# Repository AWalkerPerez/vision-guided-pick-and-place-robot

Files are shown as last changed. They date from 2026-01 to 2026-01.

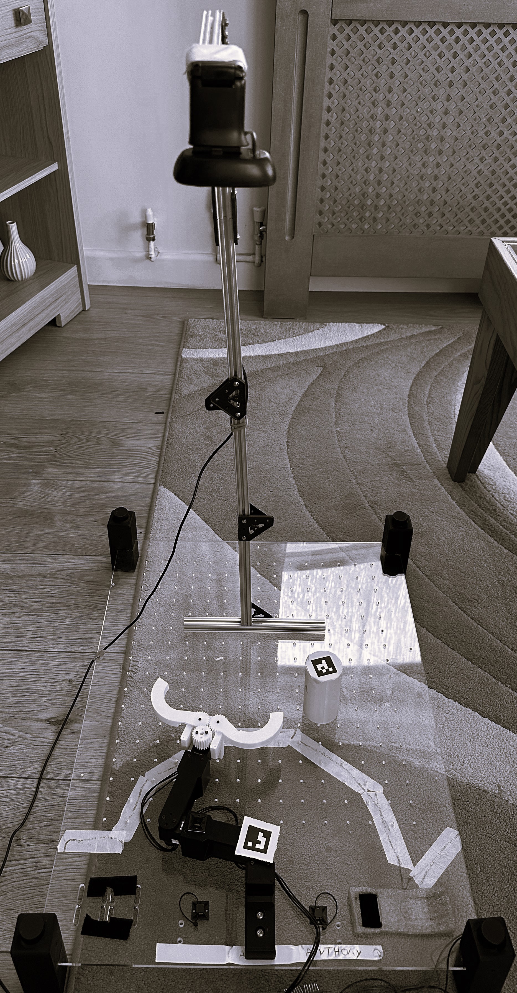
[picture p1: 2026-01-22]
media/photos/setup.jpg

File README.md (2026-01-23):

# Vision-Guided Pick-and-Place Robot (3-DOF)

Autonomous 3-DOF pick-and-place robot using **vision-based control** (ArUco markers) to localise objects and drive the robot end-effector using **inverse kinematics** (DLS / Jacobian-based control).  
This repository contains the full project deliverables: source code, CAD, calibration notes, diagrams, media, and the final report.

> ⚠️ This project is **hardware-dependent** (camera + robot). It is not designed to be simulation-only out of the box.

---

## Project overview

**Pipeline (high level):**
1. Camera captures frames of the workspace.
2. ArUco markers are detected → object pose is estimated in the camera frame.
3. Pose is transformed into the robot/world frame using calibration.
4. A controller computes joint updates (e.g., Damped Least Squares IK) to move to target.
5. Gripper/clamp action closes/opens at the right time.
6. Optional behaviours: obstacle avoidance, multi-object sequencing, homing.

---

## Repository layout

```text
vision-guided-pick-and-place-robot/
├── README.md
├── .gitignore
├── environment.md
├── setup.md
├── calibration.md
│
├── report/
│   └── AUTONOMOUS_3DOF_PICK-AND-PLACE_ROBOT_USING_VISION-BASED_CONTROL.pdf
│
├── src/
│   ├── README.md
│   ├── (your Python/ROS scripts live here)
│   └── (configs / launch / helpers depending on your implementation)
│
├── cad/
│   ├── README.md
│   └── (Fusion 360 source + exports: .f3d/.f3z, .step, .stl, .3mf)
│
├── diagrams/
│   ├── README.md
│   └── (system diagrams, flowcharts, architecture images)
│
├── media/
│   ├── README.md
│   ├── photos/
│   └── videos/
│
└── docs/
    ├── README.md
    └── (optional: extra notes, troubleshooting, design decisions)
```

---

## Quick start
### 1) Read the setup docs
- Hardware + software setup: see `setup.md`
- Environment / dependencies: see `environment.md`
- Calibration process: see `calibration.md`

### 2) Run the project (hardware required)
The entrypoint depends on how your `src/` scripts are structured (ROS nodes vs. standalone scripts).
Go to `src/README.md` for the exact run commands.

---

## Calibration
Calibration is required to map camera measurements into the robot coordinate frame and to get stable pose estimates.
See:
- `calibration.md`
- Marker PDF / reference: `aruco_markers_25mm.docx`

---

## Results & media
- Photos and videos are under `media/`.
- Diagrams and pipeline visuals are under `diagrams/`.
- Full report (methods, experiments, results): `report/`.

---

## Notes on reproducibility
Because this is a physical system, results depend on:
- camera placement + intrinsics,
- lighting conditions,
- robot assembly tolerances,
- motor tuning / controller gains,
- marker size + print quality.
The report documents the tested configuration and evaluation.

---

## Citation
If you use or reference this work, please cite the project report in `report/`.

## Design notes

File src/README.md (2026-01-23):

# src

Core ROS 2 (Python) scripts for the **vision-guided 3DOF pick-and-place robot**.

This project is **hardware-first** (camera + Dynamixel/OpenRB-150 + physical robot).  
There is no simulation workflow provided.

---

## Files

### ROS 2 nodes
- `camera_publisher.py`  
  Publishes camera frames.
  - Publishes: `camera/image` (`sensor_msgs/Image`)

- `aruco_pose.py`  
  Detects ArUco markers in `camera/image`, computes each marker pose **relative to marker ID 0**, and publishes a topic per marker ID.
  - Subscribes: `camera/image`
  - Publishes: `desired_pos_<id>` (`std_msgs/Float32MultiArray`) e.g. `desired_pos_7`
  - Parameter: `marker_size` (default **0.025 m** = 25 mm)

- `marker_tracking.py`  
  High-level **pick-and-place state machine**.
  - Subscribes: `joint_state` and dynamically subscribes to `desired_pos_<id>` topics
  - Publishes: `joint_pos`, `cartesian_pos`, `gripper_command`
  - Two stages:
    - **Stage 1 (recording):** records desired goal positions from **even marker IDs**
    - **Stage 2 (moving):** tracks objects from **odd marker IDs**
  - Pairing rule used in code:
    - Object marker `X` (odd) uses goal marker `(X + 1)` (even)

- `control_dls.py`  
  Damped Least Squares (DLS) IK controller: Cartesian target → joint targets.
  - Subscribes: `joint_state`
  - Publishes: `joint_pos`, `cartesian_pos`

- `hardware_interface.py`  
  Hardware bridge for Dynamixels via OpenRB-150.
  - Publishes: `/joint_state`, `/cartesian_pos`, `/ee_min_max`, `/emergency_stop`
  - Subscribes: `/joint_pos`, `/joint_vel`, `/joint_cur`, `/joint_pos_rel`, `/gripper_command`

### Utility (not a ROS node)
- `cameraCalibration.py`  
  Chessboard calibration utility. Saves intrinsics to `calibration.npz`.

---

## Marker pose message format (important)

`aruco_pose.py` publishes a `Float32MultiArray` with 6 values:

`[x_mm, y_mm, z_mm, roll_deg, pitch_deg, yaw_deg]`

In the current implementation, the first two values are published as:

- `msg.data[0] = relative_y_mm`
- `msg.data[1] = relative_x_mm`

`marker_tracking.py` then uses only the first two values:

- `pos = [msg.data[0], msg.data[1]]`
- `yaw = msg.data[5]`

So the system is internally consistent, but note the **X/Y ordering** is “swapped” compared to some comments.

---

## Calibration (required)

`aruco_pose.py` loads calibration like this:

```python
np.load("calibration.npz")
```
So the simplest workflow is to generate the file in the repo root and run nodes from the repo root.

Generate calibration:
```bash
python3 src/cameraCalibration.py
```
This creates:
`calibration.npz` (in your current working directory)

---

## Running the system (typical order)
Open separate terminals and ensure ROS 2 is sourced in each.

### 1) Camera publisher
```bash
python3 src/camera_publisher.py
```
### 2) Marker detection
```bash
python3 src/aruco_pose.py
```
### 3) Hardware interface (robot must be connected)
```bash
python3 src/hardware_interface.py
```
### 4) Autonomy / control
You typically run the pick-and-place state machine (and optionally DLS control depending on your test):
```bash
python3 src/marker_tracking.py
```
Optional (if you use the DLS node separately):
```bash
python3 src/control_dls.py
```

---

## Debugging quick commands
List topics:
```bash
ros2 topic list
```
Echo key topics:
```bash
ros2 topic echo /joint_state
ros2 topic echo desired_pos_0
ros2 topic echo desired_pos_1
```

---

## Common issues
**- No markers detected**

    - Check lighting / focus
    
    - Confirm printed marker size matches marker_size (25mm default)
    
    - Confirm calibration.npz exists where you run aruco_pose.py
    
    - Robot moves wrong direction / mirrored
    
    - Double-check the X/Y ordering (see message format section)
    
    - Verify camera mounting orientation and coordinate assumptions

**- Motors not responding**

    - Check device connection/permissions/port configuration inside hardware_interface.py
    
    - Confirm motor IDs and baud rate match your hardware setup

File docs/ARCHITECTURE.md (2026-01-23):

# System Architecture

This repo implements a **hardware-first** vision-guided pick-and-place pipeline for a 3DOF robot arm using:
- a top-down USB camera
- ArUco marker detection + pose estimation
- Jacobian-based IK control (Damped Least Squares)
- Dynamixel actuation via OpenRB-150
- ROS 2 (Python)

The system is split into small ROS 2 nodes that communicate via topics.

---

## Components (scripts)

The `src/` folder contains:

- `camera_publisher.py` — publishes camera frames
- `aruco_pose.py` — detects markers and publishes per-marker pose topics (`desired_pos_<id>`)
- `marker_tracking.py` — pick-and-place logic / state machine (records targets, then moves)
- `control_dls.py` — IK control (DLS) (Cartesian target → joint targets)
- `hardware_interface.py` — Dynamixel/OpenRB hardware bridge (commands + feedback + safety)
- `cameraCalibration.py` — offline chessboard calibration (creates `calibration.npz`)

---

## ROS 2 nodes and topics

### 1) Camera Publisher (`camera_publisher.py`)
**Role:** Captures frames and publishes them for vision.

- **Publishes**
  - `camera/image` (`sensor_msgs/Image`)

---

### 2) Vision / Marker Pose (`aruco_pose.py`)
**Role:** Detects markers in the camera stream and publishes their relative pose.

- **Subscribes**
  - `camera/image` (`sensor_msgs/Image`)

- **Publishes (dynamic)**
  - `desired_pos_<marker_id>` (`std_msgs/Float32MultiArray`)
  - Example topics: `desired_pos_0`, `desired_pos_1`, `desired_pos_7`, ...

**Calibration dependency**
- Loads camera intrinsics from `calibration.npz` (generated by `cameraCalibration.py`).

**Reference frame convention**
- Marker **ID 0** is used as a **reference**.
- For each detected marker, it computes pose **relative to marker 0** and publishes that.

**Message layout**
Published as `Float32MultiArray` with 6 values:
`[msg.data[0], msg.data[1], msg.data[2], msg.data[3], msg.data[4], msg.data[5]]
= [axis1_mm, axis2_mm, z_mm, roll_deg, pitch_deg, yaw_deg]`

> Note: In the current implementation the first two axes are swapped compared to the comment in-code,
> but downstream nodes treat the first two entries consistently as the “2D target position”.

---

### 3) Task Logic / State Machine (`marker_tracking.py`)
**Role:** Coordinates the autonomous behavior:
- “recording” stage: record desired goal positions
- “moving” stage: track object positions, then pick-and-place

**Dynamic subscription**
- It scans the ROS graph and automatically subscribes to any topic matching:
  - `desired_pos_<id>` or `/desired_pos_<id>`

**Marker ID convention**
- **Even marker IDs** represent **desired goal positions** (recorded during “recording” stage).
- **Odd marker IDs** represent **object markers** (tracked during “moving” stage).
- The logic pairs them like:
  - object marker `X` uses desired goal stored under marker `(X + 1)`

**Subscribes**
- `joint_state` (from hardware interface)
- `desired_pos_<id>` topics (dynamic)

**Publishes**
- `joint_pos`
- `cartesian_pos`
- `gripper_command`

---

### 4) IK Control (`control_dls.py`)
**Role:** Converts Cartesian target motion into joint commands using **Damped Least Squares**.

**Subscribes**
- `joint_state`

**Publishes**
- `joint_pos`
- `cartesian_pos`

---

### 5) Hardware Interface (`hardware_interface.py`)
**Role:** Bridge to the **physical** Dynamixel/OpenRB system:
- publishes joint feedback
- listens for motion / gripper commands
- provides safety topics

**Publishes**
- `/joint_state`
- `/cartesian_pos`
- `/ee_min_max`
- `/emergency_stop`

**Subscribes**
- `/joint_pos`
- `/joint_vel`
- `/joint_cur`
- `/joint_pos_rel`
- `/gripper_command`

> Important: Some nodes use topic names without a leading `/` (e.g. `joint_pos`),
> while the hardware node subscribes to `/joint_pos`.
> If messages don’t flow, standardise names (either always `/topic` or always `topic`)
> or check what’s actually active with `ros2 topic list`.

---

## Data-flow diagram (high level)
```
                ┌───────────────────────┐
                │    camera_publisher   │
                │  (USB/RGB camera node)│
                └───────────┬───────────┘
                            │  /camera/image
                            v
                ┌───────────────────────┐
                │    aruco_detector     │
                │ (detect IDs + pose)   │
                └───────────┬───────────┘
                            │  /aruco/poses   (pose(s) of marker(s) in camera frame)
                            v
                ┌───────────────────────┐
                │   marker_tracking     │
                │ (select target ID,    │
                │  filter/smooth pose,  │
                │  transform to robot)  │
                └───────────┬───────────┘
                            │  /target_pose   (desired end-effector pose in robot/base frame)
                            v
                ┌───────────────────────┐
                │      control_dls      │
                │ (IK / DLS / Jacobian  │
                │  -> joint commands)   │
                └───────────┬───────────┘
                            │  /joint_cmd     (q_des or dq_des)
                            v
                ┌───────────────────────┐
                │   hardware_interface  │
                │ (send to motors, read │
                │  encoders)            │
                └───────┬───────┬───────┘
                        │       │
          /joint_state  │       │  /gripper_cmd
 (q, dq feedback)       │       │  (open/close)
                        │       │
                        v       v
                ┌───────────────────────┐
                │    control_dls uses   │
                │  /joint_state feedback│
                └───────────────────────┘
```
---

## Execution order (typical)

1. `camera_publisher.py`
2. `aruco_pose.py`  (requires `calibration.npz`)
3. `hardware_interface.py` (requires physical robot connection)
4. `control_dls.py` and/or `marker_tracking.py`

---

## Suggested improvements (optional)
- Standardise topic naming (`/joint_pos` vs `joint_pos`) across all scripts.
- Replace `Float32MultiArray` for marker pose with `geometry_msgs/PoseStamped` (clearer + safer).
- Publish transforms (`tf2_ros`) for `camera → base` and marker frames for easier debugging.

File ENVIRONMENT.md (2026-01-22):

# Environment

This project is a hardware-integrated ROS2 system (camera + AprilTags + Dynamixel motors via OpenRB-150).  
It is not simulation-first; you will need the physical robot setup (or equivalent hardware) to run the full stack.

## Tested platform
- Host OS: Ubuntu (recommended: 22.04 or newer)
- ROS 2: Iron (recommended)
- Python: 3.x (ROS2 system Python)

## Core dependencies
### ROS 2 packages (typical)
- `rclpy`
- `sensor_msgs`, `geometry_msgs`, `std_msgs`
- `tf2_ros`
- `cv_bridge` (if using ROS image transport + OpenCV)
- `image_transport` (optional)

### Python packages
- `numpy`
- `opencv-python` (or system OpenCV depending on ROS install)
- AprilTag detection (one of the following depending on your implementation):
  - `apriltag` (Python wrapper), or
  - `pupil_apriltags`, or
  - OpenCV AprilTag module (if available in your build)

### Motor / hardware interface
- Dynamixel control stack as used in this project (OpenRB-150 + Dynamixel SDK / ROS wrapper depending on your implementation)

## Notes
- If you are using ROS-installed OpenCV/cv_bridge, prefer system packages over pip OpenCV to avoid ABI conflicts.
- For large binaries (videos/CAD), consider Git LFS.

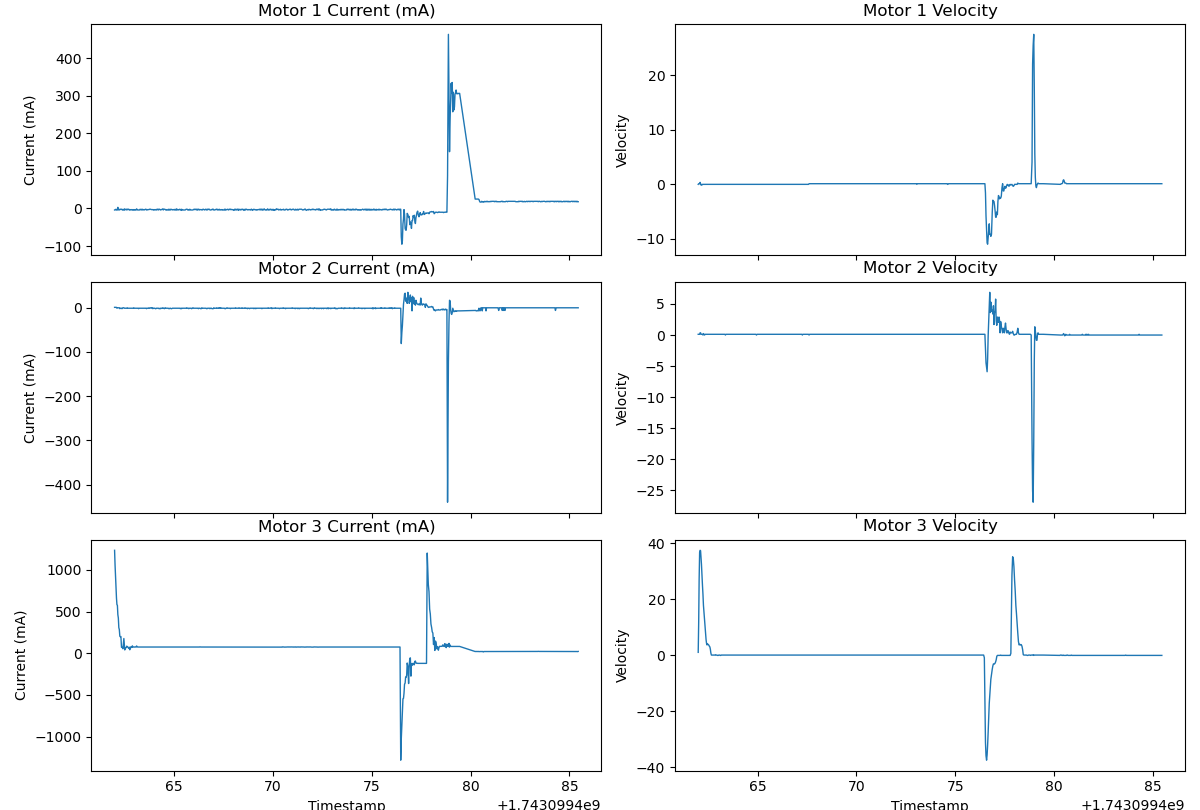
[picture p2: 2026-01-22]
docs/diagrams/motor_thresholds_200.png

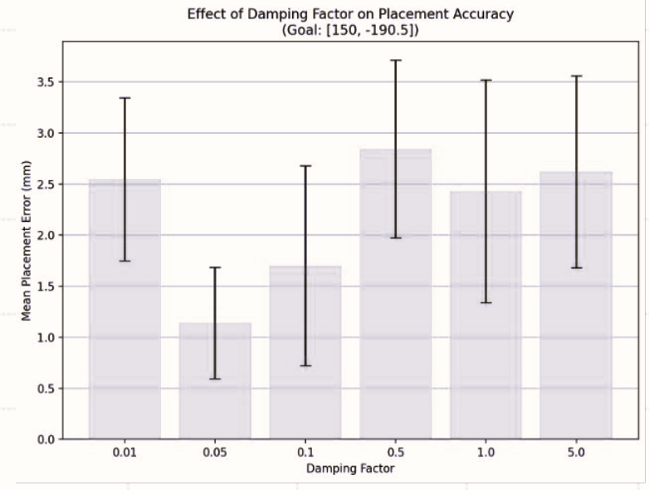
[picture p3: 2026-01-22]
docs/diagrams/damping_factor_acc_err.png

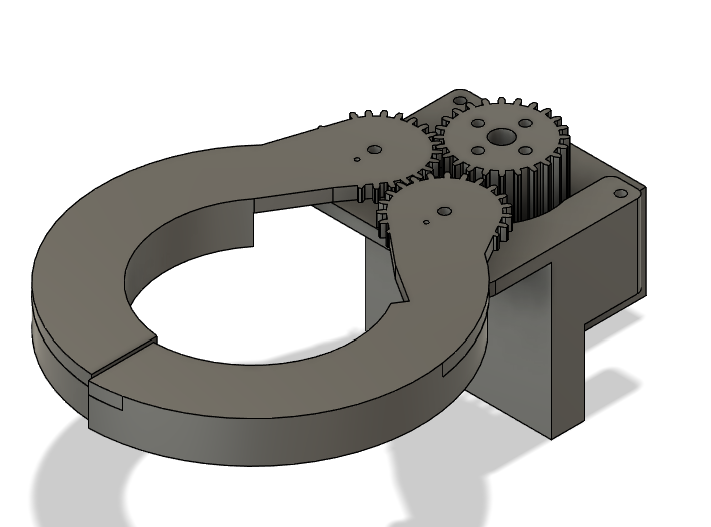
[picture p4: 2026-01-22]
media/photos/cad_end_effector.png

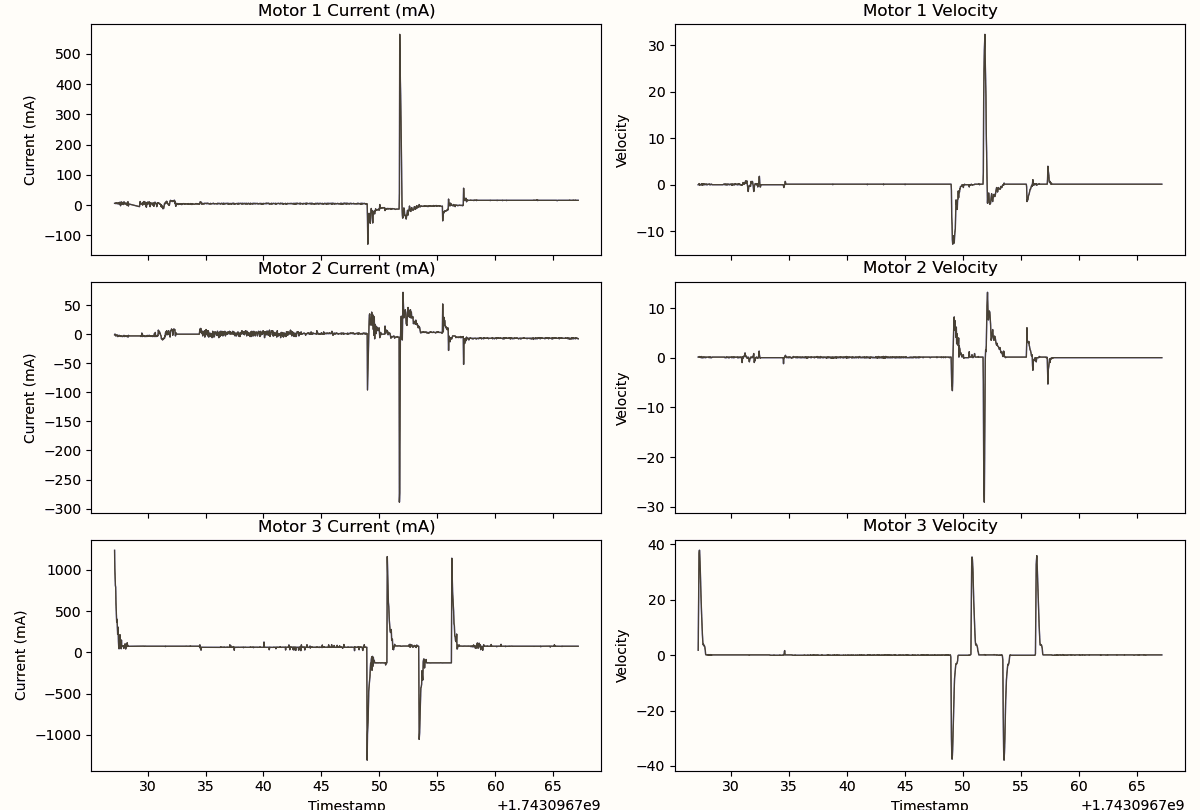
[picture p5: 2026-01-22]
docs/diagrams/motor_thresholds_no_force.png

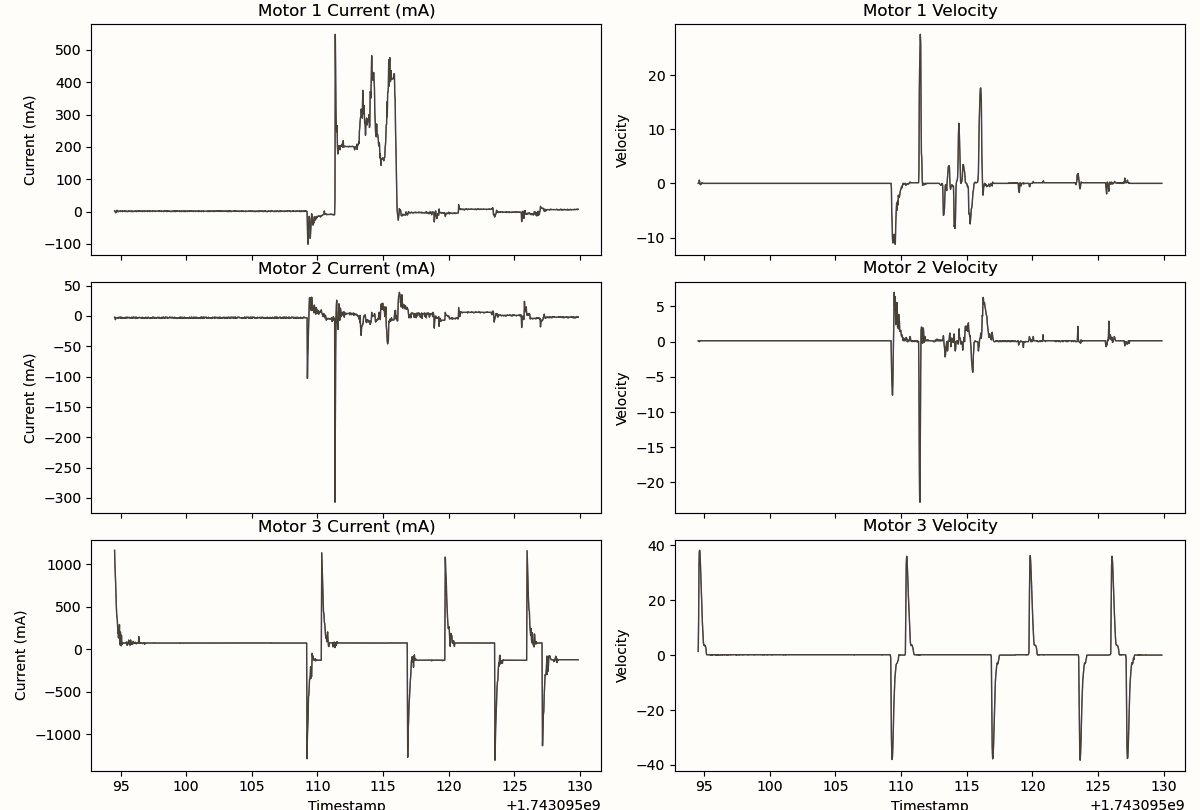
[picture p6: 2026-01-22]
docs/diagrams/motor_thresholds_force_no_threshold.png

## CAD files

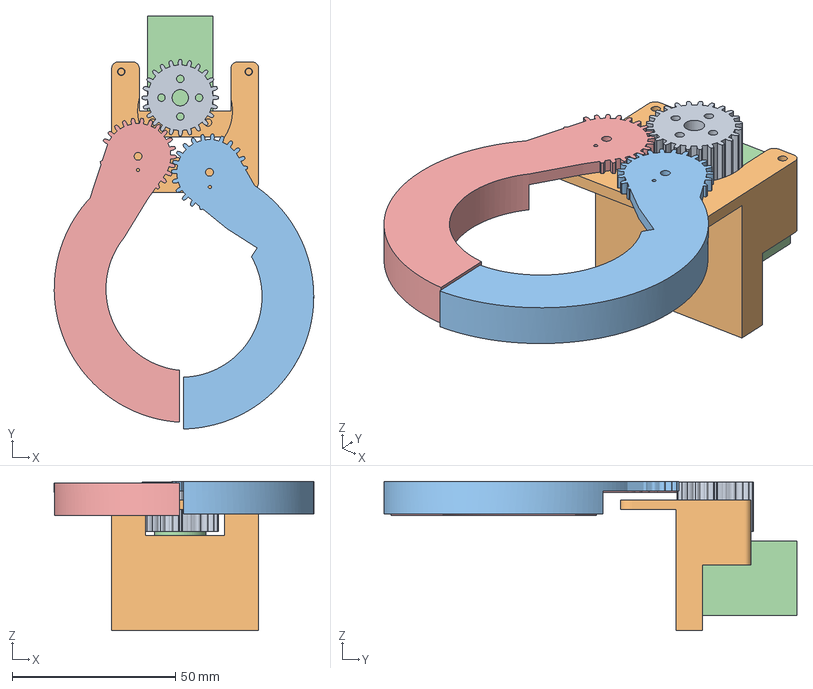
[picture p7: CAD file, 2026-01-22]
cad/printing_files/3mf/final_assembly.3mf
79.4 x 126.3 x 45.7 mm

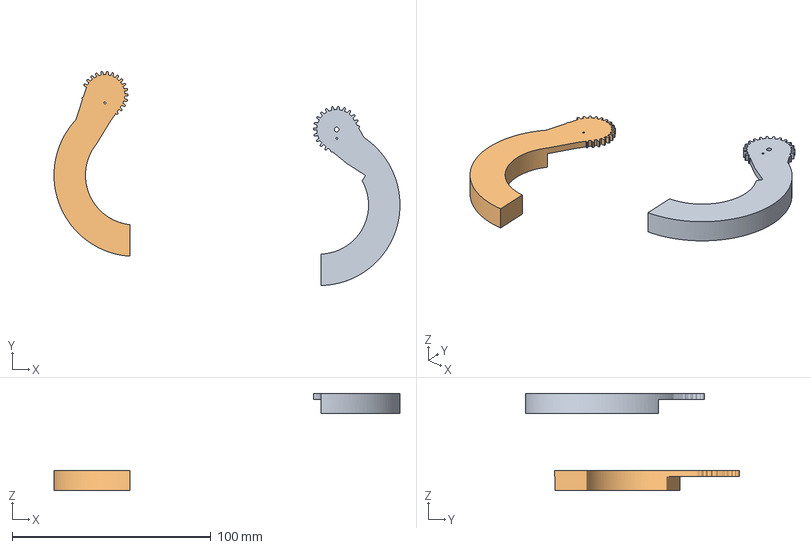
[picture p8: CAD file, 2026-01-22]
cad/printing_files/3mf/arm.3mf
174.1 x 107.7 x 48.8 mm

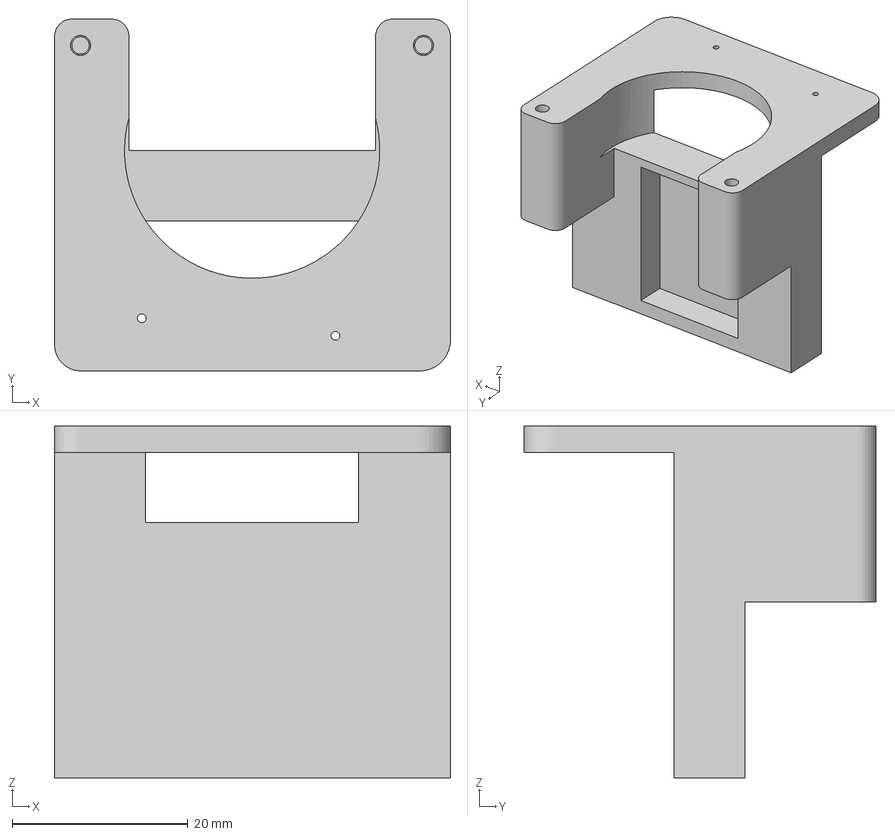
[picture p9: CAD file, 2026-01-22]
cad/printing_files/3mf/middle_piece.3mf
45.0 x 40.0 x 40.0 mm

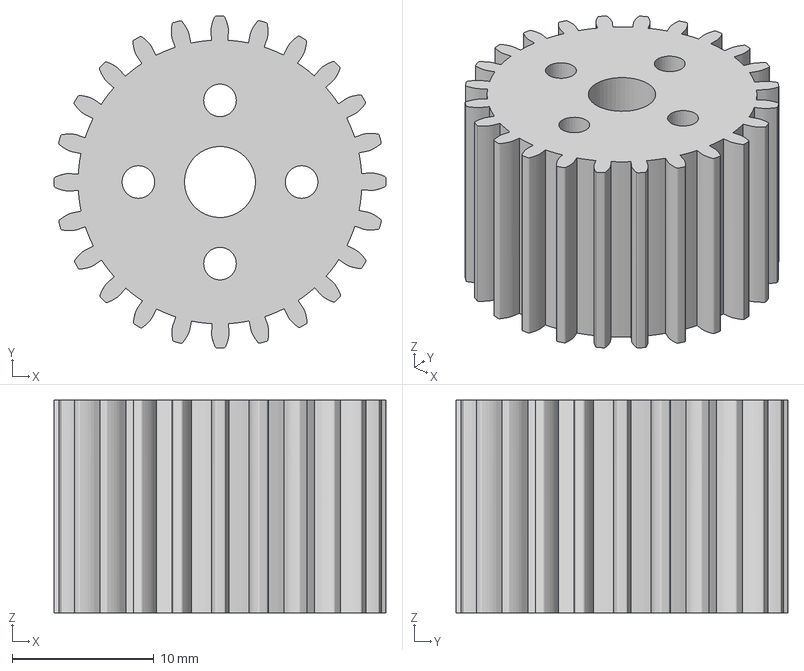
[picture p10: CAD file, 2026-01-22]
cad/printing_files/3mf/gear.3mf
23.4 x 23.4 x 15.0 mm

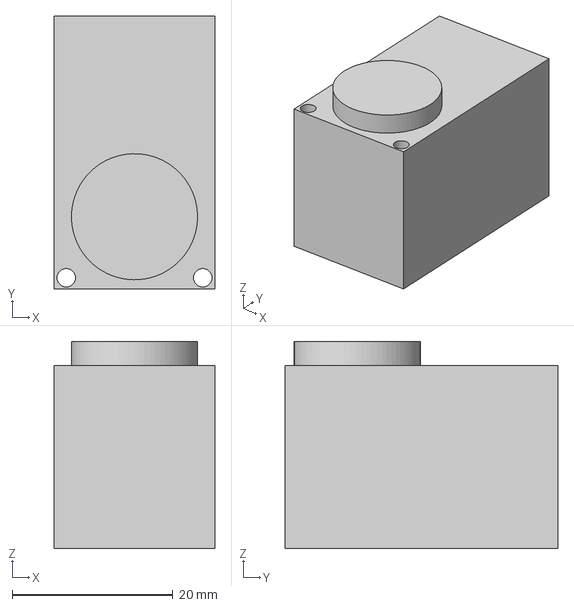
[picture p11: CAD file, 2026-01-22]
cad/printing_files/3mf/gear_holder.3mf
20.0 x 34.0 x 25.8 mm

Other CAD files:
cad/fusion360/arm.f3d
cad/fusion360/final_assembly.f3d
cad/fusion360/gear.f3d
cad/fusion360/gear_holder.f3d
cad/fusion360/middle_piece.f3d
cad/printing_files/stl/arm.stl
cad/printing_files/stl/final_assembly.stl
cad/printing_files/stl/gear.stl
cad/printing_files/stl/gear_holder.stl
cad/printing_files/stl/middle_piece.stl

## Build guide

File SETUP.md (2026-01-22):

# Setup

This repo contains a ROS2-based pick-and-place system that uses:
- A USB camera (Logitech)
- AprilTags for object detection / pose estimation
- A 3DOF arm actuated by Dynamixel motors via OpenRB-150
- Motion control using Jacobian-based IK (e.g., DLS / Jacobian Transpose depending on mode)

> This project requires hardware to run end-to-end.

---

## Hardware prerequisites
- Raspberry Pi 4 (or equivalent controller running ROS2 nodes / motor interface)
- OpenRB-150 interface board
- Dynamixel motors (as per your build)
- Motorised clamp end-effector
- USB camera (Logitech) mounted above workspace
- Printed AprilTags (see `/aruco_markers_25mm.docx` or your marker assets)
- A flat workspace with known scale + tag placement

---

## Software prerequisites
1. Install ROS2 (recommended: Iron) on the main machine(s)
2. Clone this repo
3. Install Python dependencies used by the vision/control nodes (see `environment.md`)

---

## Typical run flow (high level)
1. **Camera node**
   - Starts capturing frames and publishing images as ROS topics.

2. **Vision node**
   - Detects AprilTags, publishes tag poses (and/or TF frames).

3. **Control node**
   - Converts tag poses into target end-effector poses.
   - Runs IK (DLS / Jacobian methods) to generate joint commands.

4. **Motor interface**
   - Sends position/velocity commands to Dynamixels.
   - Reads motor feedback (current/velocity) for safety + collision handling.

---

## Calibration (recommended)
- Camera intrinsics calibration (checkerboard)
- Verify tag size matches your printed markers (e.g., 25mm / 50mm)
- Verify coordinate frames:
  - camera frame
  - world/workspace frame
  - base frame
  - end-effector frame

See: `docs/calibration.md` (create this if you don’t already have it)

---

## Safety notes
- Always test with reduced speed first.
- Ensure current-limits / stall detection is enabled before autonomous sequences.
- Keep a physical emergency stop procedure (unplug power / disable torque).

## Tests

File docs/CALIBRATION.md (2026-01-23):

# Camera Calibration (Required)

This project estimates ArUco/AprilTag marker pose from a top-down USB camera.  
To get accurate pose estimates, you must calibrate the camera intrinsics and ensure the marker size in code matches the printed markers.

Calibration is performed using:
- `src/cameraCalibration.py` (chessboard calibration)
- output file: `calibration.npz`
- used by: `src/aruco_pose.py`

---

## What calibration produces

`calibration.npz` stores:
- `camMatrix` — camera intrinsic matrix (fx, fy, cx, cy)
- `distCoef` — lens distortion coefficients

These are required for accurate marker pose estimation and stability.

---

## Prerequisites

- A printed chessboard calibration target
- Good lighting and a stable camera mount
- Python + OpenCV installed (the same OpenCV used by your project)
- A set of calibration images (or live capture, depending on how your script is written)

---

## Step 1 — Print a chessboard target

Print a chessboard pattern on A4/A3.
- Print at **100% scale** (no “fit to page”).
- Mount it flat (cardboard helps) to avoid warping.

> If your `cameraCalibration.py` expects a specific chessboard size (e.g., 7×9 corners), keep the print consistent with that.

---

## Step 2 — Capture calibration images

You need multiple images of the chessboard from different positions and angles:
- Move the chessboard across the entire camera view (corners + edges + center)
- Vary the tilt slightly (to help solve intrinsics)
- Keep the chessboard sharp and well-lit
- Avoid motion blur

Recommended: **20–40 images** minimum.

---

## Step 3 — Run calibration

From the repo root:

```bash
python3 src/cameraCalibration.py
```
This should generate:
`calibration.npz`

### Where to place calibration.npz
`aruco_pose.py` loads calibration using a relative path:

```python
np.load("calibration.npz")
```
So you have two safe options:

**Option A (simplest):** put `calibration.npz` in the repo root
✅ Works if you run scripts from the repo root.

**Option B (also fine):** put `calibration.npz` next to the script
Place it in `src/` and run `aruco_pose.py` from inside `src/`.

If you want this to be robust regardless of working directory, update `aruco_pose.py` to load calibration using an absolute path (recommended improvement).

---

## Step 4 — Verify calibration quality
After calibration, check:

### A) Visual sanity checks
- Marker detections should be stable (no sudden jumps when marker is static)
- Pose should not “flip” randomly
- Estimated distance should be reasonable (not off by 2×)

### B) Quick quantitative checks (optional)
Many calibration scripts print:
- RMS reprojection error
As a rough guide:
- **< 1.0 px** is usually decent for a typical webcam setup
- **< 0.5 px** is very good
- If it’s large (> 2–3 px), retake images with better lighting/sharpness

---

## Step 5 — Marker size consistency (very important)
Your marker size must match the printed tags.
- Printed marker document: `docs/aruco_markers_25mm.docx`
- If you use a different size (e.g., 50mm), update the marker size parameter in the vision code.
If marker size is wrong, you will see:
- incorrect depth / scale (distance estimates wrong)
- pick-and-place accuracy degraded

---

## Common issues & fixes
### “Markers detected but pose is noisy / jittery”
- Increase lighting
- Reduce motion blur (faster shutter / brighter scene)
- Ensure camera is rigidly mounted (no vibration)
- Improve calibration image quality (more images, better coverage)

### “Pose scale seems wrong”
- Marker size in code does not match printed marker size
- Chessboard print is not at 100% scale
- Wrong chessboard square size used in calibration (if your script uses square size)

### “aruco_pose.py can’t find calibration.npz”
- You ran the script from a directory where `calibration.npz` is not present
- Fix by placing `calibration.npz` in repo root or editing the load path in `aruco_pose.py`

### “OpenCV / cv_bridge import errors”
- Prefer using OpenCV consistent with your ROS install
- Avoid mixing pip OpenCV with system cv_bridge unless you know they match

---

## Recommended improvement (optional)
To make calibration loading robust, edit `aruco_pose.py` to load using an absolute path based on the script location, e.g.:
```
python
from pathlib import Path
import numpy as np

calib_path = Path(__file__).resolve().parent / "calibration.npz"
with np.load(str(calib_path)) as f:
    camMatrix = f["camMatrix"]
    distCoef = f["distCoef"]
```
This prevents “works on my machine” path issues.

---

## Next step
Once calibration is in place, run the vision node:
```bash
python3 src/aruco_pose.py
```
and confirm stable marker detection before running the full pick-and-place pipeline.

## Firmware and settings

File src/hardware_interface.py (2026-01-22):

#!/usr/bin/env python3
import rclpy
from rclpy.node import Node
from std_msgs.msg import Float32MultiArray
from dynamixel_sdk import *
import numpy as np
import time
from rclpy.qos import QoSProfile, QoSDurabilityPolicy
import os
import signal
import csv

class HardwareInterfaceNode(Node):
    def __init__(self):
        super().__init__('hardware_interface_ros')
        self.get_logger().info('Hardware interface node is alive.')

        # 40 Hz update rate
        self.timer_period = 1.0 / 40.0

        # Recovery flags
        self.in_recovery = False
        self.ignore_collision_until = 0  # temporary disable collision detection

        # Dynamixel motor control parameters
        self.ADDR_TORQUE_ENABLE    = 64
        self.ADDR_OPERATING_MODE   = 11
        self.ADDR_GOAL_CURRENT     = 102
        self.ADDR_GOAL_VELOCITY    = 104
        self.ADDR_GOAL_POSTION     = 116
        self.ADDR_PRESENT_POSITION = 132
        self.ADDR_PRESENT_VELOCITY = 128
        self.ADDR_PRESENT_CURRENT  = 126

        self.MODE_CUR = 0
        self.MODE_VEL = 1
        self.MODE_POS = 5

        self.POS_SCALING = 0.087891
        self.VEL_SCALING = 0.087891 * 0.22888 * 6
        self.CUR_SCALING = 1

        # Limits for arm joints (motors 1 and 2)
        self.LIMIT_POS = 100
        self.LIMIT_VEL = 5
        self.LIMIT_CURRENT = 500
        self.limit_pos_tol = 1

        self.BAUDRATE = 1000000
        self.DEVICENAME = '/dev/ttyACM0'
        self.ACTIVATE_MOTORS = True

        # Define motor IDs:
        self.arm_ids = [1, 2]
        self.ee_id   = 3
        self.DXL_IDs = self.arm_ids + [self.ee_id]

        # State arrays
        self.joint_pos_all = np.zeros(len(self.DXL_IDs))
        self.joint_vel_all = np.zeros(len(self.DXL_IDs))
        self.joint_cur_all = np.zeros(len(self.DXL_IDs))

        # Motor 3 calibration parameters (gripper)
        self.calibration_velocity = 20.0  # deg/s
        self.current_threshold    = 1000   # mA
        # For a tool, the gripper should remain closed initially.
        self.open_angle  = 0.0   # open angle command
        self.closed_angle = 0.0  # closed angle command

        # Collision thresholds (time-average limits)
        # For this simulation, the thresholds for motors 1 & 2 are set to trigger collision detection.
        self.collision_thresholds = {1: 150, 2: 100, 3: 2000}
        self.velocity_threshold = 0.01

        # Emergency stop publisher
        self.emergency_publisher = self.create_publisher(Float32MultiArray, '/emergency_stop', 10)

        # Initialize Dynamixel communication
        self.portHandler = PortHandler(self.DEVICENAME)
        self.packetHandler = PacketHandler(2.0)
        if not self.portHandler.openPort():
            self.get_logger().error('Failed to open port')
            quit()
        if not self.portHandler.setBaudRate(self.BAUDRATE):
            self.get_logger().error('Failed to set baudrate')
            quit()

        self.operating_mode = -1
        self.set_operating_mode(self.MODE_POS)

        # ROS Subscribers for arm control
        self.sub_angle   = self.create_subscription(Float32MultiArray, '/joint_pos', self.desired_pos_callback, 10)
        self.sub_vel     = self.create_subscription(Float32MultiArray, '/joint_vel', self.desired_vel_callback, 10)
        self.sub_cur     = self.create_subscription(Float32MultiArray, '/joint_cur', self.desired_cur_callback, 10)
        self.sub_pos_rel = self.create_subscription(Float32MultiArray, '/joint_pos_rel', self.joint_pos_rel_callback, 10)
        self.fk_publisher = self.create_publisher(Float32MultiArray, '/cartesian_pos', 10)

        # Subscriber for gripper command
        self.sub_gripper = self.create_subscription(Float32MultiArray, '/gripper_command', self.gripper_command_callback, 10)

        # Publishers for joint state and calibration feedback
        self.publisher = self.create_publisher(Float32MultiArray, '/joint_state', 10)
        qos_profile = QoSProfile(depth=1, durability=QoSDurabilityPolicy.TRANSIENT_LOCAL)
        self.ee_pub = self.create_publisher(Float32MultiArray, '/ee_min_max', qos_profile)

        # Timer for periodic joint state updates
        self.timer = self.create_timer(self.timer_period, self.joint_state_callback)
        self.motor_modes = {id: None for id in self.DXL_IDs}

        # Initialize motors to initial positions
        # For arm motors, home position is (90, -90). For the gripper, we start in the closed state.
        initial_positions = {1: 90.0, 2: -90.0, 3: self.closed_angle}
        for id, angle in initial_positions.items():
            self.set_pos(id, angle)

        time.sleep(2.0)
        self.calibrate_motor3()

        # Initialize current history dictionary (1-second window)
        self.current_history = {id: [] for id in self.DXL_IDs}

        # CSV Logging Setup: Save to /home/pi/ws/motor_thresholds_log_force_3.csv
        save_dir = "/home/pi/ws"
        os.makedirs(save_dir, exist_ok=True)
        log_file_path = os.path.join(save_dir, "motor_thresholds_log_force_3.csv")
        self.log_file = open(log_file_path, "w", newline="")
        self.csv_writer = csv.writer(self.log_file)
        self.csv_writer.writerow(["timestamp", "motor_id", "current_mA", "velocity"])
        self.get_logger().info(f"Logging motor thresholds to {log_file_path}")

    def shutdown_procedure(self):
        self.get_logger().info("Shutdown procedure initiated.")
        if hasattr(self, 'log_file') and not self.log_file.closed:
            self.log_file.close()
            self.get_logger().info("CSV log file closed successfully.")
        self.destroy_node()
        rclpy.shutdown()

    def calibrate_motor3(self):
        while True:
            self.get_logger().info("Starting motor 3 calibration...")
            self.set_operating_mode_for_motor(self.ee_id, self.MODE_VEL)
            self.move_until_obstruction(direction=1)
            self.closed_angle = self.get_pos(self.ee_id)
            self.move_until_obstruction(direction=-1)
            self.open_angle = self.get_pos(self.ee_id)
            angle_diff = abs(self.open_angle - self.closed_angle)
            self.get_logger().info(f"Calibration result: Open={self.open_angle:.2f}°, Closed={self.closed_angle:.2f}°, Difference={angle_diff:.2f}°")
            if angle_diff >= 5.0:
                break
            self.get_logger().warn("Calibration failed: Difference between open and closed angle is less than 5 degrees. Re-calibrating...")
            time.sleep(1.0)  # Optional delay before retrying

        # Publish calibration result
        ee_msg = Float32MultiArray()
        ee_msg.data = [self.open_angle, self.closed_angle]
        self.ee_pub.publish(ee_msg)
        self.get_logger().info(f"Calibration complete: Open={self.open_angle:.2f}°, Closed={self.closed_angle:.2f}°")
        self.set_operating_mode_for_motor(self.ee_id, self.MODE_POS)
        self.set_pos(self.ee_id, self.closed_angle)

    def set_operating_mode_for_motor(self, motor_id, mode):
        if self.motor_modes[motor_id] == mode:
            return
        self.packetHandler.write1ByteTxRx(self.portHandler, motor_id, self.ADDR_TORQUE_ENABLE, 0)
        self.packetHandler.write1ByteTxRx(self.portHandler, motor_id, self.ADDR_OPERATING_MODE, mode)
        if self.ACTIVATE_MOTORS:
            self.packetHandler.write1ByteTxRx(self.portHandler, motor_id, self.ADDR_TORQUE_ENABLE, 1)
        self.motor_modes[motor_id] = mode
        time.sleep(0.1)

    def move_until_obstruction(self, direction=1):
        vel_cmd = int(direction * self.calibration_velocity / self.VEL_SCALING)
        self.packetHandler.write4ByteTxRx(self.portHandler, self.ee_id, self.ADDR_GOAL_VELOCITY, vel_cmd)
        while True:
            current = abs(self.get_cur(self.ee_id))
            if current >= self.current_threshold:
                self.packetHandler.write4ByteTxRx(self.portHandler, self.ee_id, self.ADDR_GOAL_VELOCITY, 0)
                time.sleep(0.5)
                if direction == -1:
                    nudge_vel = int(direction * (self.calibration_velocity * 0.2) / self.VEL_SCALING)
                    self.packetHandler.write4ByteTxRx(self.portHandler, self.ee_id, self.ADDR_GOAL_VELOCITY, nudge_vel)
                    time.sleep(0.2)
                    self.packetHandler.write4ByteTxRx(self.portHandler, self.ee_id, self.ADDR_GOAL_VELOCITY, 0)
                break
            time.sleep(0.01)

    def set_pos(self, id, pos):
        self.set_operating_mode_for_motor(id, self.MODE_POS)
        if id in self.arm_ids:
            if pos > self.LIMIT_POS:
                pos = self.LIMIT_POS
            elif pos < -self.LIMIT_POS:
                pos = -self.LIMIT_POS
        pos_cmd = int((pos + 180.0) / self.POS_SCALING)
        self.packetHandler.write4ByteTxRx(self.portHandler, id, self.ADDR_GOAL_POSTION, pos_cmd)

    def set_vel(self, id, vel):
        self.set_operating_mode(self.MODE_VEL)
        if id in self.arm_ids:
            if vel > self.LIMIT_VEL:
                vel = self.LIMIT_VEL
            elif vel < -self.LIMIT_VEL:
                vel = -self.LIMIT_VEL
        vel_cmd = int(vel / self.VEL_SCALING)
        self.packetHandler.write4ByteTxRx(self.portHandler, id, self.ADDR_GOAL_VELOCITY, vel_cmd)

    def set_cur(self, id, cur):
        self.set_operating_mode(self.MODE_CUR)
        if id in self.arm_ids:
            if cur > self.LIMIT_CURRENT:
                cur = self.LIMIT_CURRENT
            elif cur < -self.LIMIT_CURRENT:
                cur = -self.LIMIT_CURRENT
        self.packetHandler.write2ByteTxRx(self.portHandler, id, self.ADDR_GOAL_CURRENT, int(cur))

    def set_operating_mode(self, mode):
        if mode == self.operating_mode:
            return 1
        for id in self.DXL_IDs:
            self.packetHandler.write1ByteTxRx(self.portHandler, id, self.ADDR_TORQUE_ENABLE, 0)
            self.packetHandler.write1ByteTxRx(self.portHandler, id, self.ADDR_OPERATING_MODE, mode)
            if self.ACTIVATE_MOTORS:
                self.packetHandler.write1ByteTxRx(self.portHandler, id, self.ADDR_TORQUE_ENABLE, 1)
            mode_actual, _, _ = self.packetHandler.read1ByteTxRx(self.portHandler, id, self.ADDR_OPERATING_MODE)
        if mode_actual == mode:
            self.operating_mode = mode_actual
            self.get_logger().info("Updated mode to %d" % self.operating_mode)
            return 1
        else:
            self.get_logger().info("Failed to update mode")
            return 0

    # ---------------------------
    # Arm Control Callbacks
    # ---------------------------
    def desired_pos_callback(self, pos_msg):
        targets = pos_msg.data
        if len(targets) != len(self.arm_ids):
            self.get_logger().info("Number of given angles doesn't match number of arm motors")
            return
        for idx, id in enumerate(self.arm_ids):
            self.set_pos(id, targets[idx])

    def desired_vel_callback(self, vel_msg):
        targets = vel_msg.data
        if len(targets) != len(self.arm_ids):
            self.get_logger().info("Number of given velocities doesn't match number of arm motors")
            return
        for idx, id in enumerate(self.arm_ids):
            predicted_pos = self.get_pos(id) + self.timer_period * self.get_vel(id)
            if (predicted_pos > self.LIMIT_POS and targets[idx] > 0.0) or (predicted_pos < -self.LIMIT_POS and targets[idx] < 0.0):
                self.set_vel(id, 0.0)
            else:
                self.set_vel(id, targets[idx])

    def forward_kinematics(self, angles):
        theta = np.radians(angles)
        l = [100, 155]
        x = l[0] * np.cos(theta[0]) + l[1] * np.cos(theta[0] + theta[1])
        y = l[0] * np.sin(theta[0]) + l[1] * np.sin(theta[0] + theta[1])
        return [x, y]

    def desired_cur_callback(self, cur_msg):
        targets = cur_msg.data
        if len(targets) != len(self.arm_ids):
            self.get_logger().info("Number of given currents doesn't match number of arm motors")
            return
        for idx, id in enumerate(self.arm_ids):
            self.set_cur(id, targets[idx])

    def joint_pos_rel_callback(self, pos_rel_msg):
        rel_positions = pos_rel_msg.data
        if len(rel_positions) != len(self.arm_ids):
            self.get_logger().info("Mismatch in the number of arm joints and relative position commands")
            return
        for idx, id in enumerate(self.arm_ids):
            current_pos = self.get_pos(id)
            target_pos = current_pos + rel_positions[idx]
            if target_pos > self.LIMIT_POS:
                target_pos = self.LIMIT_POS
            elif target_pos < -self.LIMIT_POS:
                target_pos = -self.LIMIT_POS
            self.set_pos(id, target_pos)

    # ---------------------------
    # Gripper Control Callback
    # ---------------------------
    def gripper_command_callback(self, msg):
        if len(msg.data) < 1:
            self.get_logger().warn("Received empty gripper command")
            return
        ratio = max(0.0, min(1.0, msg.data[0]))
        target_pos = self.closed_angle + (self.open_angle - self.closed_angle) * ratio
        self.get_logger().info(f"Gripper command: ratio={ratio}, target_pos={target_pos}")
        self.set_pos(self.ee_id, target_pos)
        tolerance = 20.0
        current_gripper_pos = self.get_pos(self.ee_id)
        if abs(current_gripper_pos - self.closed_angle) < tolerance:
            self.carrying_object = True
            self.get_logger().info("Gripper is closed: Object is being carried.")
        else:
            self.carrying_object = False
            self.get_logger().info("Gripper is open: No object is being carried.")

    # ---------------------------
    # Motor State Reading Methods
    # ---------------------------
    def get_pos(self, id):
        pos, _, _ = self.packetHandler.read4ByteTxRx(self.portHandler, id, self.ADDR_PRESENT_POSITION)
        return float(pos) * self.POS_SCALING - 180.0

    def get_vel(self, id):
        vel, _, _ = self.packetHandler.read4ByteTxRx(self.portHandler, id, self.ADDR_PRESENT_VELOCITY)
        return float(self.s16(vel)) * self.VEL_SCALING

    def get_cur(self, id):
        cur, _, _ = self.packetHandler.read2ByteTxRx(self.portHandler, id, self.ADDR_PRESENT_CURRENT)
        if cur > 1750:
            cur -= 2**16
        return cur

    def s16(self, value):
        return -(value & 0x8000) | (value & 0x7fff)

    # ---------------------------
    # Recovery Method: Moves arm to home then opens gripper
    # ---------------------------
    def recover_home(self):
        self.get_logger().info("Recovering: moving to home positions.")
        # Disable collision detection for 2 seconds
        self.ignore_collision_until = time.time() + 2.0
        # Clear current history
        self.current_history = {motor_id: [] for motor_id in self.DXL_IDs}

        # Phase 1: Move arm joints to home positions (using angles, not Cartesian points)
        # Here, motor 1 is set to 90° and motor 2 is set to -90°.
        home_positions_arm = {1: 90.0, 2: -90.0}
        for motor_id, angle in home_positions_arm.items():
            self.set_pos(motor_id, angle)
        # Keep the gripper closed initially
        self.set_pos(self.ee_id, self.closed_angle)
        self.get_logger().info("Arm joints reached home position. Now opening gripper.")

        # Phase 2: Open the gripper (motor 3)
        self.set_pos(self.ee_id, self.open_angle)
        self.get_logger().info("Recovery complete: Home positions commanded and gripper opened.")

    # ---------------------------
    # Periodic Joint State Callback (with CSV logging and collision check)
    # ---------------------------
    def joint_state_callback(self):
        if self.in_recovery:
            return

        current_time = time.time()
        state_msg = Float32MultiArray()
        for idx, id in enumerate(self.DXL_IDs):
            self.joint_pos_all[idx] = self.get_pos(id)
            self.joint_vel_all[idx] = self.get_vel(id)
            self.joint_cur_all[idx] = self.get_cur(id)
            self.get_logger().info(
                f"Motor {id}: Current = {self.joint_cur_all[idx]:.2f} mA, Velocity = {self.joint_vel_all[idx]:.2f}"
            )
            self.current_history[id].append((current_time, abs(self.joint_cur_all[idx])))
            self.current_history[id] = [(t, c) for (t, c) in self.current_history[id] if current_time - t <= 2.0]

        for id in self.arm_ids:
            index = self.DXL_IDs.index(id)
            if self.joint_pos_all[index] >= self.LIMIT_POS or self.joint_pos_all[index] <= -self.LIMIT_POS:
                self.get_logger().info(f"Arm Joint {id} at or beyond limit: Position = {self.joint_pos_all[index]}")

        if self.operating_mode == self.MODE_VEL:
            for id in self.arm_ids:
                index = self.DXL_IDs.index(id)
                predicted_pos = self.joint_pos_all[index] + self.timer_period * self.joint_vel_all[index]
                if (predicted_pos > (self.LIMIT_POS + self.limit_pos_tol)) and (self.joint_vel_all[index] > 0.0):
                    self.set_vel(id, 0.0)
                elif (predicted_pos < (-self.LIMIT_POS + self.limit_pos_tol)) and (self.joint_vel_all[index] < 0.0):
                    self.set_vel(id, 0.0)

        # Modified collision detection: For arm motors, trigger recovery when average current exceeds threshold (ignoring velocity)
        if current_time >= self.ignore_collision_until:
            for motor_id in self.DXL_IDs:
                idx = self.DXL_IDs.index(motor_id)
                history = self.current_history[motor_id]
                if history:
                    avg_current = sum(c for t, c in history) / len(history)
                    threshold = self.collision_thresholds.get(motor_id, 1000)
                    if motor_id in self.arm_ids:
                        velocity = abs(self.joint_vel_all[idx])
                        if avg_current > threshold and velocity < self.velocity_threshold:
                            self.get_logger().warn(
                                f"Collision detected on Arm Motor {motor_id}! Avg Current = {avg_current:.2f} mA, Velocity = {velocity:.2f}"
                            )
                            self.set_vel(motor_id, 0.0)
                            self.get_logger().info("Collision detected on arm. Initiating recovery (rehoming).")
                            self.in_recovery = True
                            self.recover_home()
                            self.in_recovery = False
                            return
                    else:
                        velocity = abs(self.joint_vel_all[idx])
                        if avg_current > threshold and velocity > self.velocity_threshold:
                            self.get_logger().warn(
                                f"Collision detected on Motor {motor_id}! Avg Current = {avg_current:.2f} mA, Velocity = {velocity:.2f}"
                            )
                            self.set_vel(motor_id, 0.0)
                            self.get_logger().info("Collision detected. Initiating recovery.")
                            self.in_recovery = True
                            self.recover_home()
                            self.in_recovery = False
                            return

        state_msg.data.extend(self.joint_pos_all)
        state_msg.data.extend(self.joint_vel_all)
        state_msg.data.extend(self.joint_cur_all)

        arm_angles = [self.joint_pos_all[self.DXL_IDs.index(id)] for id in self.arm_ids]
        cartesian_pos = self.forward_kinematics(arm_angles)
        cartesian_msg = Float32MultiArray()
        cartesian_msg.data = [float(cartesian_pos[0]), float(cartesian_pos[1])]
        self.fk_publisher.publish(cartesian_msg)

        self.publisher.publish(state_msg)

        timestamp = time.time()
        for id in self.DXL_IDs:
            idx = self.DXL_IDs.index(id)
            current_val = self.joint_cur_all[idx]
            velocity_val = self.joint_vel_all[idx]
            self.csv_writer.writerow([f"{timestamp:.3f}", id, f"{current_val:.2f}", f"{velocity_val:.2f}"])
        self.log_file.flush()

def main(args=None):
    rclpy.init(args=args)
    node = HardwareInterfaceNode()

    def signal_handler(sig, frame):
        node.get_logger().info(f"Signal {sig} received, shutting down.")
        node.shutdown_procedure()

    signal.signal(signal.SIGINT, signal_handler)
    signal.signal(signal.SIGTERM, signal_handler)

    try:
        rclpy.spin(node)
    except Exception as e:
        node.get_logger().error(f"Exception in spin: {e}")
    finally:
        if rclpy.ok():
            node.shutdown_procedure()

if __name__ == '__main__':
    main()
